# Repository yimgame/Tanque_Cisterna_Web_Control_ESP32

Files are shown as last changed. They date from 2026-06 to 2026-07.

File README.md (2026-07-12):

# Control de bomba para tanque con cisterna por ESP32

Proyecto para controlar una bomba con una ESP32, dos sensores ultrasónicos y un relé. El sistema publica una interfaz web en la propia placa para ver el estado del tanque y la cisterna, habilitar control manual, cambiar el WiFi y acceder por IP o por mDNS.

## Qué incluye

- Servidor web local en la ESP32.
- Medición de cisterna y tanque en tiempo real.
- Modo automático con lógica de llenado.
- Arranque manual con modal de confirmación.
- Arranque manual directo del relé (independiente de niveles), con corte por tiempo máximo.
- Cambio de credenciales WiFi desde ruta oculta de configuración.
- Ruta `/log` con bitácora de acciones (IP, fecha/hora cuando hay NTP).
- Histograma de consumo de agua estimado por hora.
- Acceso por IP local y por `http://tanque.local/`.

## Materiales

- 1 ESP32 compatible, por ejemplo NodeMCU 32S.
- 2 sensores ultrasónicos.
- 1 relé para la bomba.
- Fuente y cableado adecuados para tu instalación.

## Requisitos

1. Instala y abre **[Arduino IDE](https://docs.arduino.cc/software/ide/)**.
2. Configura el soporte de ESP32 en el IDE.
3. Si tu placa no comunica, instala el driver correcto, por ejemplo **[WCH CH340 Driver](https://www.tecneu.com/blogs/tutoriales-de-electronica/guia-paso-a-paso-para-instalar-el-driver-ch340g-en-windows-y-mac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)** o **[Silicon Labs CP210x](https://community.silabs.com/s/question/0D58Y00008K88dCSAR/how-to-download-cp210x-usb-to-uart-bridge-vcp-drivers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)**.
4. Asegúrate de tener las librerías necesarias para ESP32 y WiFiManager.

## Uso

1. Abre el proyecto en Arduino IDE.
2. Compila y sube el sketch que está en [sketch/sketch.ino](sketch/sketch.ino).
3. La primera vez, la ESP32 abrirá el portal de WiFiManager para conectar a tu red.
4. Una vez conectada, revisa el monitor serie: ahí verás la IP local y la URL de acceso.
5. También puedes entrar desde la web con la IP mostrada o con `http://tanque.local/` si tu red resuelve mDNS.

## Prueba rápida

- En el simulador de Wokwi puedes probar la lógica y mover los sensores.
- Proyecto de referencia: https://wokwi.com/projects/467575637641711617

## Nota sobre red

La interfaz web ya no depende de editar manualmente `ssid` y `password`. La red se gestiona con WiFiManager.

Para cambiar credenciales guardadas, entra a la ruta oculta `http://tanque.local/config` (o `http://IP_LOCAL/config`) y usa la opción **CAMBIAR WIFI**.

En esa misma pantalla también puedes guardar la configuración de control del sistema:

- Diámetro y altura de tanque y cisterna.
- Caudal de la bomba en L/min.
- Distancia de lleno y vacío para tanque y cisterna.
- Distancia actual medida por cada sensor.

El sketch calcula la capacidad de cada depósito a partir de diámetro y altura, y usa la calibración de distancias para determinar los arranques y paradas.

En esa misma ruta `/config` tienes el acceso a **VER LOG**, que abre `http://tanque.local/log`.

La conexión queda en DHCP por defecto para que el autoconectado sea más estable, pero ahora también puedes cargar IP manual desde el mismo portal.

### Modo simultáneo: DHCP + IP manual

En el portal de WiFiManager verás los campos de IP, gateway, máscara y DNS.

1. Si dejas esos campos vacíos, la ESP32 conecta por DHCP (automático).
2. Si completas esos campos, la ESP32 conecta con IP manual (estática).

### Opcional avanzado: IP manual por código

Si prefieres dejar fija la IP desde el código, el sketch también está preparado con un ejemplo.

1. Abre [sketch/sketch.ino](sketch/sketch.ino).
2. Busca el bloque `CONFIGURACIÓN DE IP MANUAL (ESTÁTICA)`.
3. Descomenta estas 4 líneas y ajusta los valores a tu red:
	- `IP_MANUAL(192, 168, 0, 34)`
	- `GW_MANUAL(192, 168, 0, 1)`
	- `MASK_MANUAL(255, 255, 255, 0)`
	- `DNS_MANUAL(8, 8, 8, 8)`
4. En `setup()`, descomenta esta línea:
	- `wifiManager.setSTAStaticIPConfig(IP_MANUAL, GW_MANUAL, MASK_MANUAL, DNS_MANUAL);`
5. Compila y vuelve a subir el sketch.

Si dejas todo comentado, seguirá usando el modo simultáneo del portal (DHCP por defecto con opción manual).

## Control manual y seguridad

1. El botón **ARRANQUE** muestra un modal de advertencia antes de activar el relé.
2. Al confirmar, el relé puede encender en modo manual directo (salta la lógica automática de niveles).
3. El botón **PARADA** corta el relé manual.
4. El botón **AUTO / RESET** vuelve al modo automático.
5. El límite de seguridad de 10 minutos sigue activo incluso en modo manual directo.

## Logs y consumo

1. Entra a `http://tanque.local/config`.
2. Abre **VER LOG** para ir a `http://tanque.local/log`.
3. Allí verás la bitácora de comandos con acción, IP cliente y marca de tiempo.
4. También verás un histograma de consumo estimado (L/h), calculado por variación del tanque.
5. Si no hay hora sincronizada por red, la marca de tiempo se guarda como uptime.

## Primera conexión

1. Conéctate desde el celular o PC a la red WiFi que levanta la ESP32 (portal de WiFiManager).
2. Elige tu red WiFi de casa y escribe la contraseña.
3. Guarda y sal del portal. La red temporal de la ESP32 se cierra.
4. Vuelve a conectarte a tu red normal y entra a `http://tanque.local` o a la IP mostrada por el monitor serie.

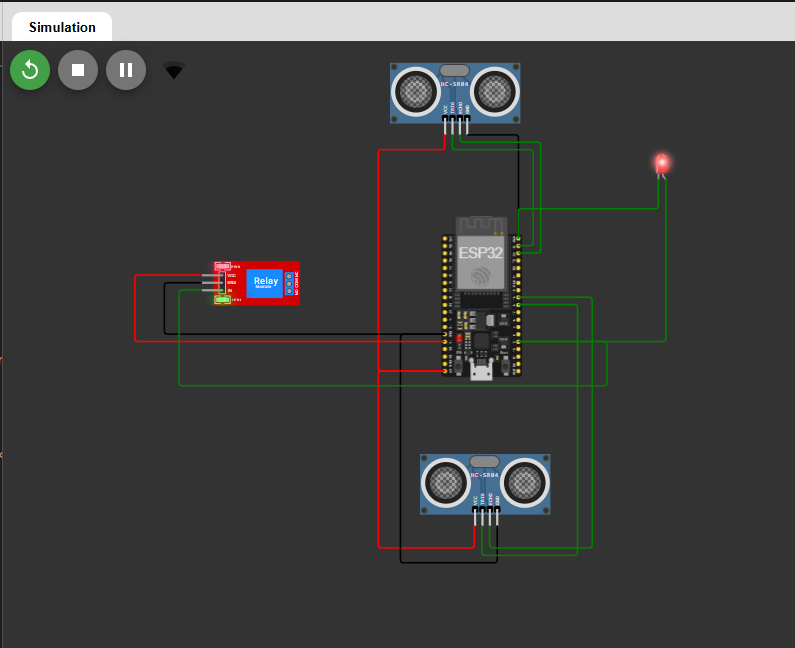
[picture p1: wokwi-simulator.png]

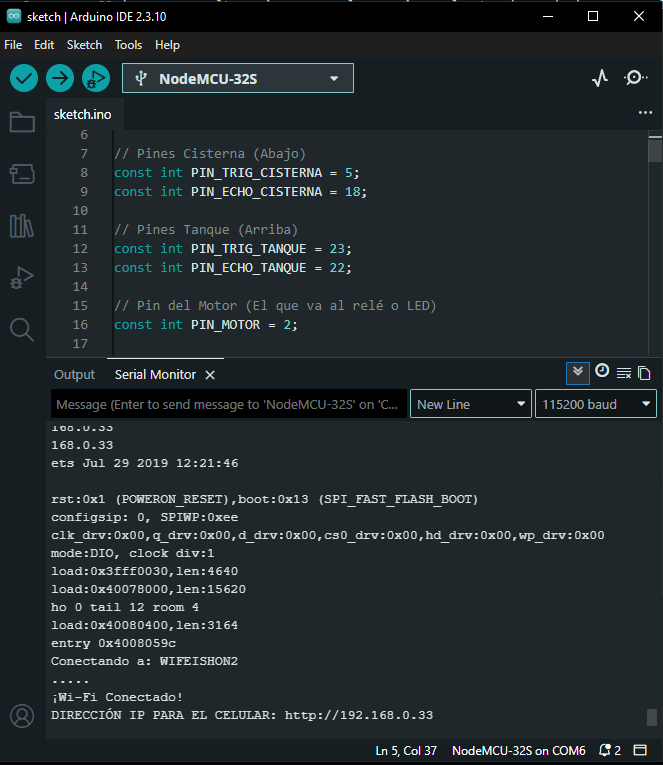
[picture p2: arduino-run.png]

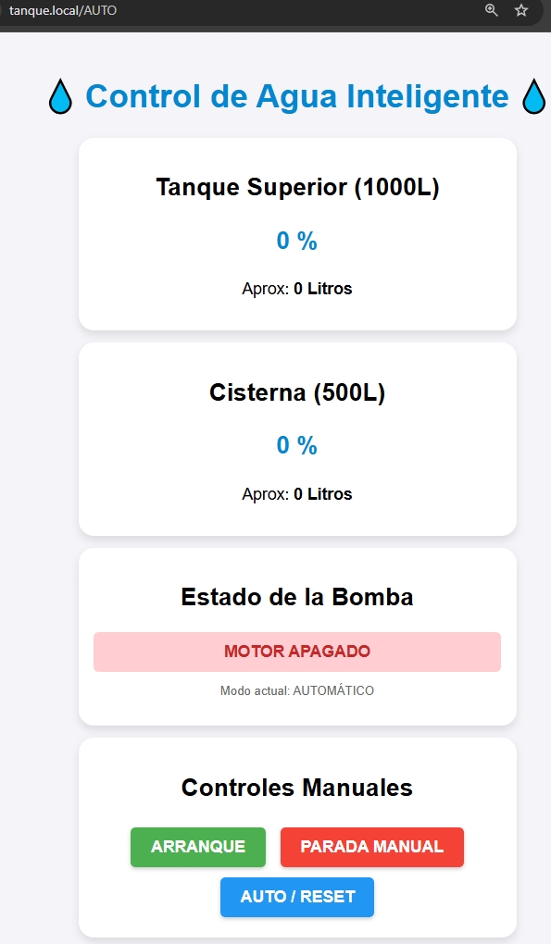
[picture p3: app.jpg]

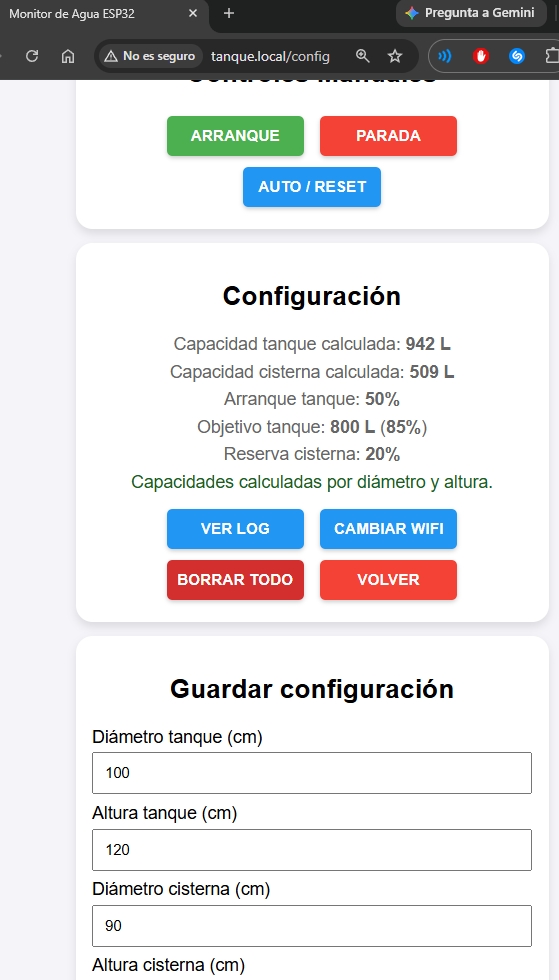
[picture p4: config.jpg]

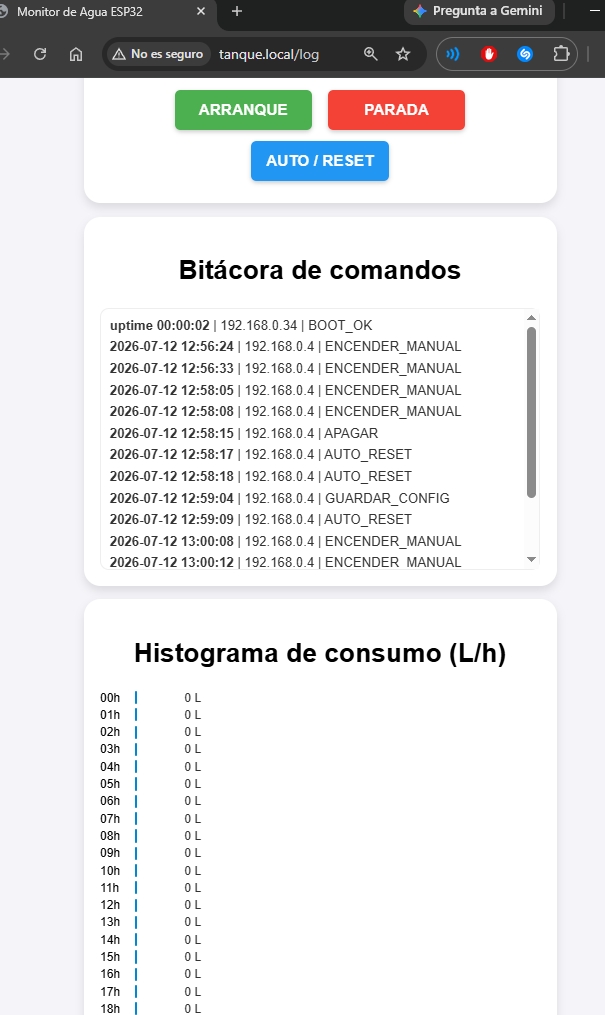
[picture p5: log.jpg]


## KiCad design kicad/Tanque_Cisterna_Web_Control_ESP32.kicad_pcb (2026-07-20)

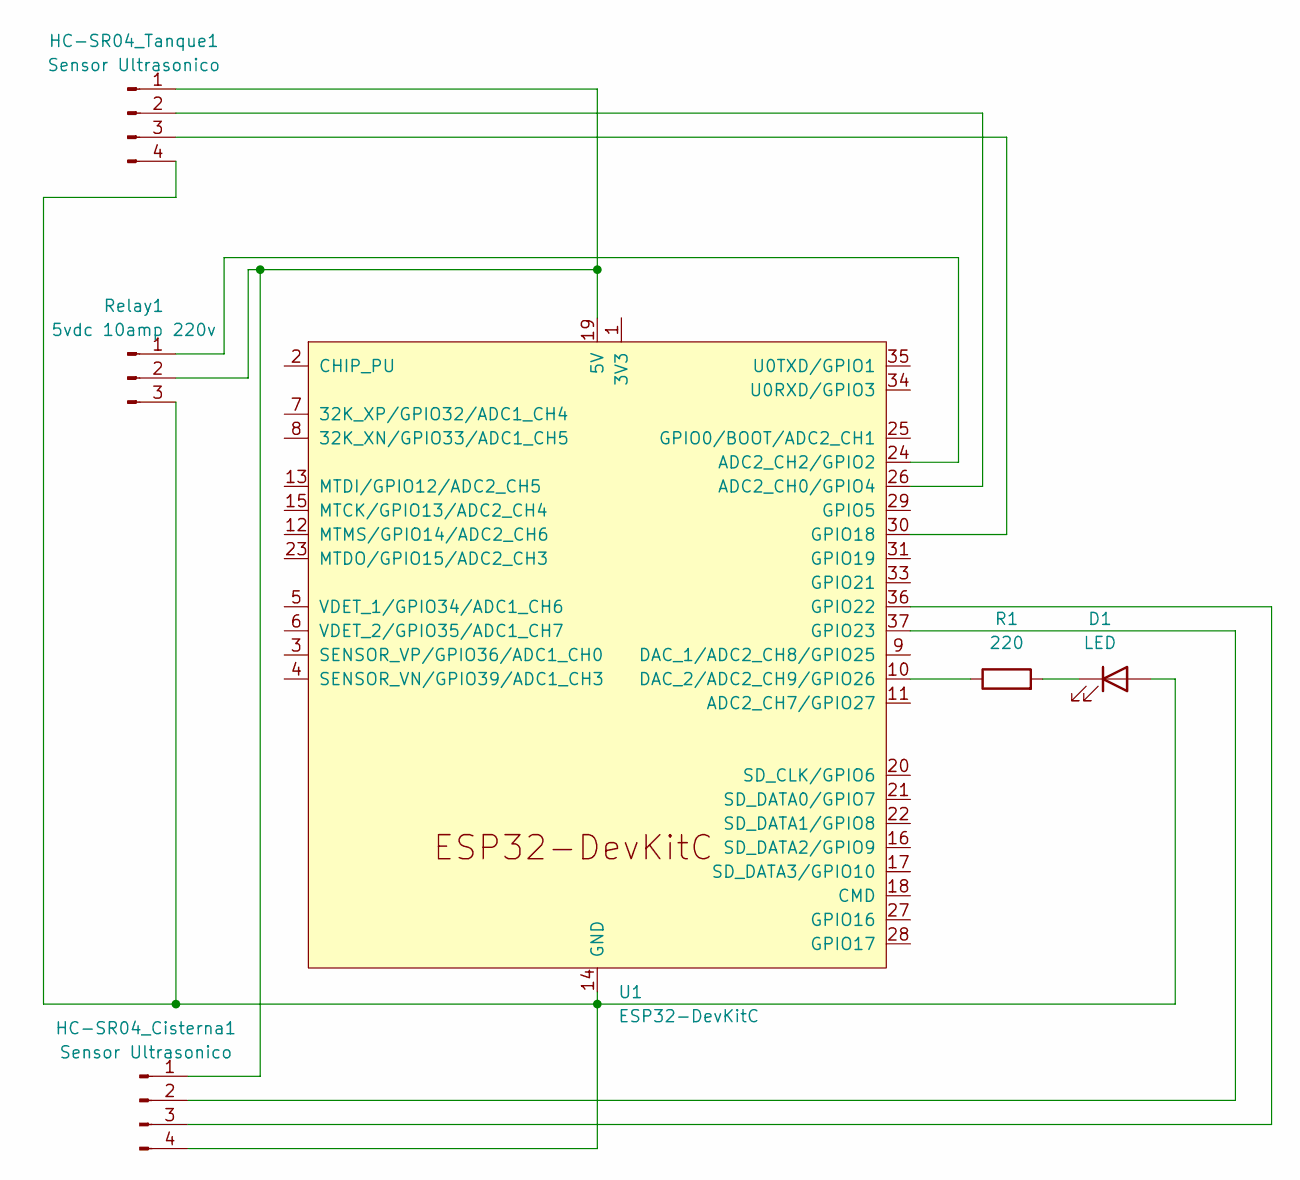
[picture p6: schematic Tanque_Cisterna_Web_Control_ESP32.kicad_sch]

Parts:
D1: LED; LED_D5.0mm
HC-SR04_Cisterna1, HC-SR04_Tanque1: Sensor Ultrasonico; PinSocket_1x04_P2.54mm_Vertical
R1: 220; R_Axial_DIN0207_L6.3mm_D2.5mm_P7.62mm_Horizontal
Relay1: 5vdc 10amp 220v; PinSocket_1x03_P2.54mm_Vertical
U1: ESP32-DevKitC

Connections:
unnamed: D1.2 (A), HC-SR04_Cisterna1.4, HC-SR04_Tanque1.4, Relay1.3, U1.14 (GND), U1.32 (GND), U1.38 (GND)
unnamed: D1.1 (K), R1.2
unnamed: HC-SR04_Cisterna1.1, HC-SR04_Tanque1.1, Relay1.2, U1.19 (5V)
unnamed: HC-SR04_Cisterna1.2, U1.37 (GPIO23)
unnamed: HC-SR04_Cisterna1.3, U1.36 (GPIO22)
unnamed: HC-SR04_Tanque1.2, U1.26 (ADC2_CH0/GPIO4)
unnamed: HC-SR04_Tanque1.3, U1.30 (GPIO18)
unnamed: Relay1.1, U1.24 (ADC2_CH2/GPIO2)
unnamed: R1.1, U1.10 (DAC_2/ADC2_CH9/GPIO26)

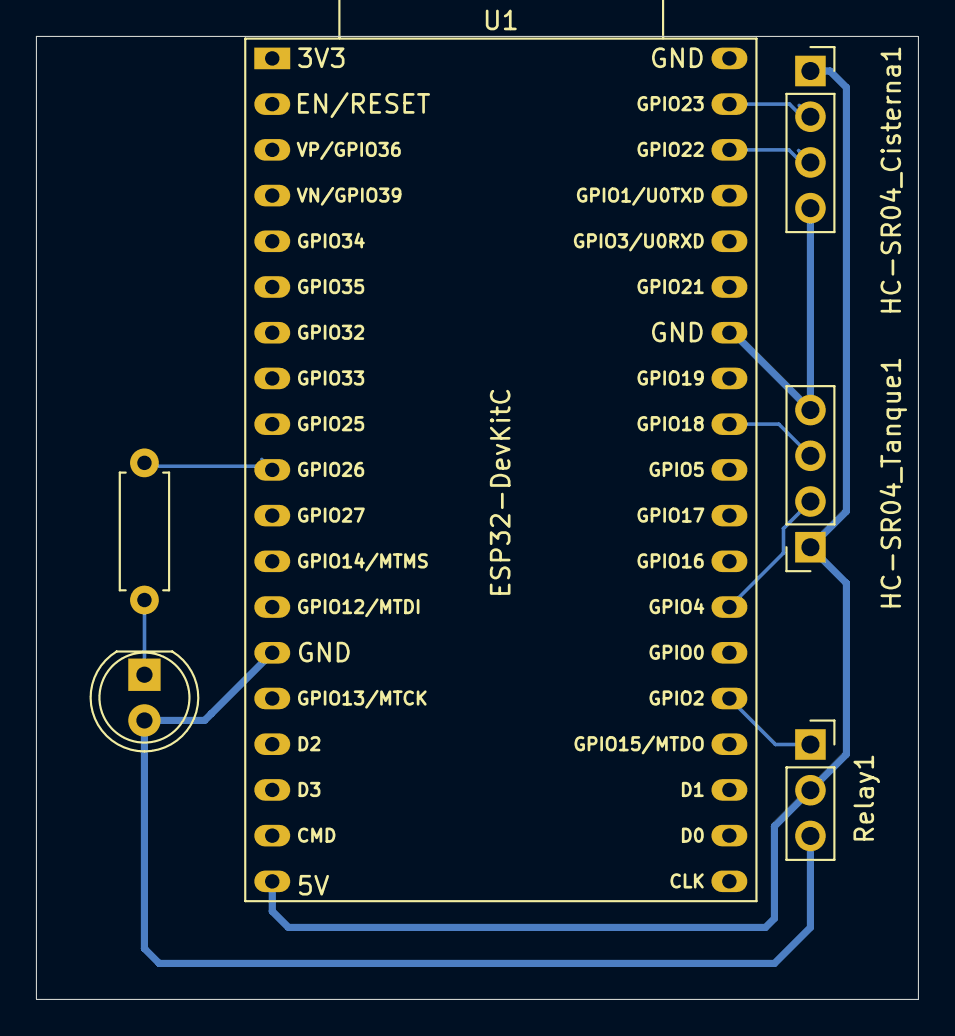
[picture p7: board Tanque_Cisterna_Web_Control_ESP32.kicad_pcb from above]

Board: 2 copper layers, 49.0 x 53.5 mm, 6 parts (0 on the bottom side), 9 nets.

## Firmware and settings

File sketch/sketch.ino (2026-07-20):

#include <DNSServer.h> // Servidor DNS para el portal de configuración WiFiManager
#include <ESPmDNS.h>   // mDNS para "tanque.local"
#include <Preferences.h> // Librería para almacenamiento persistente en la memoria flash del ESP32
#include <WebServer.h>   // Servidor web para la interfaz de usuario
#include <WiFi.h>        // Librería WiFi para ESP32
#include <WiFiManager.h> // Configuración wifi
#include <time.h> // Librería para obtener la hora de red (NTP) y formatearla

// Pines Cisterna (Abajo)
const int PIN_TRIG_CISTERNA = 4;
const int PIN_ECHO_CISTERNA = 18;

// Pines Tanque (Arriba)
const int PIN_TRIG_TANQUE = 23;
const int PIN_ECHO_TANQUE = 22;

// Pin del Motor
const int PIN_MOTOR = 2;

// Pin del LED
const int PIN_LED = 26; // led de motor funcionando prende cuando arranca y se
                        // apaga cuando se detiene

// --- CONFIGURACIÓN DEL SISTEMA ---
const int CAPACIDAD_CISTERNA_FALLBACK_LITROS = 100;
const int CAPACIDAD_TANQUE_FALLBACK_LITROS = 100;

// Valores geométricos y de control por defecto
const int DIAMETRO_CISTERNA_DEF_CM = 50;
const int ALTURA_CISTERNA_DEF_CM = 90;
const int DIAMETRO_TANQUE_DEF_CM = 50;
const int ALTURA_TANQUE_DEF_CM = 90;
const float CAUDAL_BOMBA_DEF_LPM = 20.0f;

// Nuevos parámetros de control unificados en porcentajes
const int TANQUE_ARRANQUE_DEF_PORCENTAJE = 10;  // Default 10%
const int TANQUE_CORTE_DEF_PORCENTAJE = 95;     // Default 95%
const int CISTERNA_RESERVA_DEF_PORCENTAJE = 10; // Default 10%
const int CISTERNA_MAX_DEF_PORCENTAJE = 95;     // Default 95%

const int CAPTURAS_PROMEDIO_DEF = 10;
const int CAPTURAS_PROMEDIO_MAX = 50;
const int TIEMPO_ESPERA_ENTRE_ARRANQUES_DEF_MIN = 60;
const int TIEMPO_ESPERA_ENTRE_ARRANQUES_MIN_MIN = 5;
const int TIEMPO_ESPERA_ENTRE_ARRANQUES_MAX_MIN = 240;

int diametroCisternaCm = DIAMETRO_CISTERNA_DEF_CM;
int alturaCisternaCm = ALTURA_CISTERNA_DEF_CM;
int diametroTanqueCm = DIAMETRO_TANQUE_DEF_CM;
int alturaTanqueCm = ALTURA_TANQUE_DEF_CM;
float caudalBombaLpm = CAUDAL_BOMBA_DEF_LPM;

int tanqueArranquePorcentaje = TANQUE_ARRANQUE_DEF_PORCENTAJE;
int tanqueCortePorcentaje = TANQUE_CORTE_DEF_PORCENTAJE;
int cisternaReservaPorcentaje = CISTERNA_RESERVA_DEF_PORCENTAJE;
int cisternaMaxPorcentaje = CISTERNA_MAX_DEF_PORCENTAJE;

int capturasPromedio = CAPTURAS_PROMEDIO_DEF;
int tiempoEsperaEntreArranquesMin = TIEMPO_ESPERA_ENTRE_ARRANQUES_DEF_MIN;

int muestrasCisterna[CAPTURAS_PROMEDIO_MAX] = {0};
int muestrasTanque[CAPTURAS_PROMEDIO_MAX] = {0};
long sumaMuestrasCisterna = 0;
long sumaMuestrasTanque = 0;
int indiceMuestra = 0;
int cantidadMuestras = 0;

const unsigned long TIEMPO_SEGURIDAD_MINIMO_BOMBA_MS = 10UL * 60UL * 1000UL;
const unsigned long TIEMPO_SEGURIDAD_MINIMO_CALCULADO_MS = 60UL * 1000UL;
const float FACTOR_SEGURIDAD_BOMBA = 1.2f;

// --- VARIABLES DE ESTADO ---
bool motorEncendido = false;
bool bloqueoSeguridad = false;
bool reiniciarParaConfigWiFi = false;
bool releManualDirecto = false;
bool pedidoArranqueAutomatico = false;
unsigned long tiempoInicioBomba = 0;
unsigned long tiempoFuncionando = 0;
unsigned long tiempoMaximoBombaMs = TIEMPO_SEGURIDAD_MINIMO_BOMBA_MS;
unsigned long proximoArranquePermitidoMs = 0;
String accesoWebIp = "";
String accesoWebMdns = "http://tanque.local/";
unsigned long ultimaSalidaSerialSensores = 0;
const unsigned long INTERVALO_SERIAL_SENSORES_MS = 1000;

int modoManual = 0;

WiFiManager wifiManager;
Preferences preferences;
String mensajeConfig = "";

// --- LOGS Y CONSUMO DE AGUA ---
const int MAX_LOGS = 40;
const unsigned long INTERVALO_CONSUMO_MS = 30000;

struct EventoLog {
  String momento;
  String ip;
  String accion;
};

EventoLog logs[MAX_LOGS];
int logInicio = 0;
int logCantidad = 0;
float histConsumoLitros[24] = {0};
unsigned long ultimoMuestreoConsumo = 0;
int ultimoLitrosTanqueMuestreo = -1;

void guardarHistorialConsumo() {
  preferences.begin("consumo", false);
  preferences.putBytes("hist24", histConsumoLitros, sizeof(histConsumoLitros));
  preferences.end();
}

void cargarHistorialConsumo() {
  preferences.begin("consumo", true);
  size_t leidos = preferences.getBytes("hist24", histConsumoLitros,
                                       sizeof(histConsumoLitros));
  preferences.end();

  if (leidos != sizeof(histConsumoLitros)) {
    for (int i = 0; i < 24; i++) {
      histConsumoLitros[i] = 0;
    }
  }
}

void borrarHistorialConsumo() {
  for (int i = 0; i < 24; i++) {
    histConsumoLitros[i] = 0;
  }
  guardarHistorialConsumo();
}

void borrarPersistenciaConsumo() {
  preferences.begin("consumo", false);
  preferences.remove("hist24");
  preferences.end();
  borrarHistorialConsumo();
}

String marcaTiempoActual() {
  struct tm info;
  if (getLocalTime(&info, 5)) {
    char buffer[24];
    strftime(buffer, sizeof(buffer), "%Y-%m-%d %H:%M:%S", &info);
    return String(buffer);
  }

  unsigned long totalSeg = millis() / 1000;
  unsigned long hh = totalSeg / 3600;
  unsigned long mm = (totalSeg % 3600) / 60;
  unsigned long ss = totalSeg % 60;
  char buffer[24];
  snprintf(buffer, sizeof(buffer), "uptime %02lu:%02lu:%02lu", hh, mm, ss);
  return String(buffer);
}

String obtenerRazonReinicio() {
  esp_reset_reason_t reason = esp_reset_reason();
  switch (reason) {
  case ESP_RST_POWERON:
    return "Encendido (Power-on)";
  case ESP_RST_EXT:
    return "Pin de Reset (External pin)";
  case ESP_RST_SW:
    return "Reinicio por Software";
  case ESP_RST_PANIC:
    return "Excepcion de Software (Crash)";
  case ESP_RST_INT_WDT:
    return "Watchdog de Interrupcion";
  case ESP_RST_TASK_WDT:
    return "Watchdog de Tarea (Task WDT)";
  case ESP_RST_WDT:
    return "Otros Watchdogs";
  case ESP_RST_DEEPSLEEP:
    return "Despierto de Deep Sleep";
  case ESP_RST_BROWNOUT:
    return "Baja Tension (Brownout)";
  case ESP_RST_SDIO:
    return "Reset SDIO";
  default:
    return "Desconocido";
  }
}

void registrarEvento(const String &accion, const String &ip) {
  int idx = (logInicio + logCantidad) % MAX_LOGS;
  logs[idx].momento = marcaTiempoActual();
  logs[idx].ip = ip;
  logs[idx].accion = accion;

  if (logCantidad < MAX_LOGS) {
    logCantidad++;
  } else {
    logInicio = (logInicio + 1) % MAX_LOGS;
  }
}

int obtenerHoraHistograma() {
  struct tm info;
  if (getLocalTime(&info, 5)) {
    return info.tm_hour;
  }
  return (millis() / 3600000UL) % 24;
}

void actualizarHistogramaConsumo(int litrosTanque) {
  unsigned long ahora = millis();
  if (ultimoLitrosTanqueMuestreo < 0) {
    ultimoLitrosTanqueMuestreo = litrosTanque;
    ultimoMuestreoConsumo = ahora;
    return;
  }

  if (ahora - ultimoMuestreoConsumo < INTERVALO_CONSUMO_MS) {
    return;
  }

  int delta = ultimoLitrosTanqueMuestreo - litrosTanque;
  if (delta >= 2) {
    int h = obtenerHoraHistograma();
    histConsumoLitros[h] += delta;
    guardarHistorialConsumo();
  }

  ultimoLitrosTanqueMuestreo = litrosTanque;
  ultimoMuestreoConsumo = ahora;
}

String obtenerRutaSolicitud(const String &request) {
  int inicio = request.indexOf("GET /");
  if (inicio < 0)
    return "";
  int fin = request.indexOf(' ', inicio + 5);
  if (fin < 0)
    return "";
  return request.substring(inicio + 5, fin);
}

String obtenerParametroConsulta(const String &ruta, const String &nombre) {
  int pregunta = ruta.indexOf('?');
  if (pregunta < 0)
    return "";
  String consulta = ruta.substring(pregunta + 1);
  String marca = nombre + "=";
  int inicio = consulta.indexOf(marca);
  if (inicio < 0)
    return "";
  inicio += marca.length();
  int fin = consulta.indexOf('&', inicio);
  if (fin < 0)
    fin = consulta.length();
  String valor = consulta.substring(inicio, fin);
  valor.replace("+", " ");
  return valor;
}

int leerParametroEntero(const String &ruta, const String &nombre,
                        int valorActual, int minimo, int maximo) {
  String valor = obtenerParametroConsulta(ruta, nombre);
  if (valor.length() == 0)
    return valorActual;
  return constrain(valor.toInt(), minimo, maximo);
}

float leerParametroFloat(const String &ruta, const String &nombre,
                         float valorActual, float minimo, float maximo) {
  String valor = obtenerParametroConsulta(ruta, nombre);
  if (valor.length() == 0)
    return valorActual;
  float nuevoValor = valor.toFloat();
  return constrain(nuevoValor, minimo, maximo);
}

int calcularCapacidadCilindricaLitros(int diametroCm, int alturaCm,
                                      int capacidadFallbackLitros) {
  if (diametroCm <= 0 || alturaCm <= 0)
    return capacidadFallbackLitros;
  float radioCm = diametroCm / 2.0f;
  float volumenCm3 = 3.14159265f * radioCm * radioCm * alturaCm;
  int litros = (int)(volumenCm3 / 1000.0f + 0.5f);
  return (litros <= 0) ? capacidadFallbackLitros : litros;
}

// NUEVA FUNCIÓN: Traduce el porcentaje deseado a distancia física en cm
// basándose en la altura total
int calcularDistanciaDesdePorcentaje(int porcentaje, int alturaTotalCm) {
  if (alturaTotalCm <= 0)
    return 0;
  float factorVacío = (100.0f - porcentaje) / 100.0f;
  return (int)(alturaTotalCm * factorVacío + 0.5f);
}

// Nueva lectura limpia del porcentaje según la lectura actual del sensor y la
// física del contenedor
int calcularPorcentajeDesdeMedicion(int distanciaCm, int alturaTotalCm) {
  if (alturaTotalCm <= 0)
    return 0;
  int distanciaAjustada = constrain(distanciaCm, 0, alturaTotalCm);
  float pct =
      ((float)(alturaTotalCm - distanciaAjustada) / alturaTotalCm) * 100.0f;
  return constrain((int)(pct + 0.5f), 0, 100);
}

void reiniciarPromedioSensores() {
  sumaMuestrasCisterna = 0;
  sumaMuestrasTanque = 0;
  indiceMuestra = 0;
  cantidadMuestras = 0;
}

unsigned long obtenerCooldownAnticicloMs() {
  int minutos = constrain(tiempoEsperaEntreArranquesMin,
                          TIEMPO_ESPERA_ENTRE_ARRANQUES_MIN_MIN,
                          TIEMPO_ESPERA_ENTRE_ARRANQUES_MAX_MIN);
  return (unsigned long)minutos * 60UL * 1000UL;
}

unsigned long obtenerCooldownRestanteMs() {
  if (proximoArranquePermitidoMs == 0)
    return 0;
  unsigned long ahora = millis();
  if (ahora >= proximoArranquePermitidoMs)
    return 0;
  return proximoArranquePermitidoMs - ahora;
}

String obtenerTextoEstadoBomba() {
  if (bloqueoSeguridad)
    return "BLOQUEO DE SEGURIDAD";
  unsigned long cooldownRestanteMs = obtenerCooldownRestanteMs();
  if (cooldownRestanteMs > 0 && !motorEncendido && modoManual == 0 &&
      !releManualDirecto) {
    return "EN COOLDOWN - restan " +
           String((cooldownRestanteMs / 1000UL) / 60) + " min " +
           String((cooldownRestanteMs / 1000UL) % 60) + " seg";
  }
  if (motorEncendido)
    return "BOMBEANDO AGUA...";
  return "MOTOR APAGADO";
}

bool guardarConfiguracionDesdeRuta(const String &ruta, String &error) {
  int nuevoDiametroTanqueCm =
      leerParametroEntero(ruta, "diam_tanque", diametroTanqueCm, 0, 500);
  int nuevaAlturaTanqueCm =
      leerParametroEntero(ruta, "alto_tanque", alturaTanqueCm, 1, 500);
  int nuevoDiametroCisternaCm =
      leerParametroEntero(ruta, "diam_cisterna", diametroCisternaCm, 0, 500);
  int nuevaAlturaCisternaCm =
      leerParametroEntero(ruta, "alto_cisterna", alturaCisternaCm, 1, 500);
  float nuevoCaudalBombaLpm =
      leerParametroFloat(ruta, "caudal_bomba", caudalBombaLpm, 0.1f, 9999.0f);

  int nuevoTanqueArranquePorcentaje = leerParametroEntero(
      ruta, "tanque_arranque_pct", tanqueArranquePorcentaje, 0, 100);
  int nuevoTanqueCortePorcentaje = leerParametroEntero(
      ruta, "tanque_corte_pct", tanqueCortePorcentaje, 0, 100);
  int nuevaCisternaReservaPct = leerParametroEntero(
      ruta, "cisterna_reserva_pct", cisternaReservaPorcentaje, 0, 100);
  int nuevaCisternaMaxPct = leerParametroEntero(ruta, "cisterna_max_pct",
                                                cisternaMaxPorcentaje, 0, 100);

  int nuevasCapturasPromedio = leerParametroEntero(
      ruta, "capturas_promedio", capturasPromedio, 1, CAPTURAS_PROMEDIO_MAX);
  int nuevoCooldownAnticicloMin = leerParametroEntero(
      ruta, "cooldown_anticiclo_min", tiempoEsperaEntreArranquesMin,
      TIEMPO_ESPERA_ENTRE_ARRANQUES_MIN_MIN,
      TIEMPO_ESPERA_ENTRE_ARRANQUES_MAX_MIN);

  if (nuevoTanqueArranquePorcentaje >= nuevoTanqueCortePorcentaje) {
    error = "El % de arranque del tanque debe ser menor que el % de corte.";
    return false;
  }
  if (nuevaCisternaReservaPct >= nuevaCisternaMaxPct) {
    error = "La reserva de la cisterna debe ser menor al % máximo de la misma.";
    return false;
  }

  diametroTanqueCm = nuevoDiametroTanqueCm;
  alturaTanqueCm = nuevaAlturaTanqueCm;
  diametroCisternaCm = nuevoDiametroCisternaCm;
  alturaCisternaCm = nuevaAlturaCisternaCm;
  caudalBombaLpm = nuevoCaudalBombaLpm;
  tanqueArranquePorcentaje = nuevoTanqueArranquePorcentaje;
  tanqueCortePorcentaje = nuevoTanqueCortePorcentaje;
  cisternaReservaPorcentaje = nuevaCisternaReservaPct;
  cisternaMaxPorcentaje = nuevaCisternaMaxPct;
  tiempoEsperaEntreArranquesMin = nuevoCooldownAnticicloMin;

  if (capturasPromedio != nuevasCapturasPromedio) {
    capturasPromedio = nuevasCapturasPromedio;
    reiniciarPromedioSensores();
  }

  preferences.begin("tanquecfg", false);
  preferences.putInt("diam_tanque", diametroTanqueCm);
  preferences.putInt("alto_tanque", alturaTanqueCm);
  preferences.putInt("diam_cisterna", diametroCisternaCm);
  preferences.putInt("alto_cisterna", alturaCisternaCm);
  preferences.putFloat("caudal_bomba", caudalBombaLpm);
  preferences.putInt("tanque_arranque_pct", tanqueArranquePorcentaje);
  preferences.putInt("tanque_corte_pct", tanqueCortePorcentaje);
  preferences.putInt("cisterna_reserva_pct", cisternaReservaPorcentaje);
  preferences.putInt("cisterna_max_pct", cisternaMaxPorcentaje);
  preferences.putInt("cooldown_anticiclo_min", tiempoEsperaEntreArranquesMin);
  preferences.putInt("capt_prom", capturasPromedio);
  preferences.end();
  error = "";
  return true;
}
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
void loop() {
  int lecturaCisterna = medirDistancia(PIN_TRIG_CISTERNA, PIN_ECHO_CISTERNA);
  int lecturaTanque = medirDistancia(PIN_TRIG_TANQUE, PIN_ECHO_TANQUE);
  agregarMuestrasSensores(lecturaCisterna, lecturaTanque);

  int capacidadCisternaLitros = calcularCapacidadCilindricaLitros(
      diametroCisternaCm, alturaCisternaCm, CAPACIDAD_CISTERNA_FALLBACK_LITROS);
  int capacidadTanqueLitros = calcularCapacidadCilindricaLitros(
      diametroTanqueCm, alturaTanqueCm, CAPACIDAD_TANQUE_FALLBACK_LITROS);

  // Mapeos dinámicos basados exclusivamente en la altura y lectura de los
  // sensores
  int pctCisterna =
      calcularPorcentajeDesdeMedicion(distCisterna, alturaCisternaCm);
  int pctTanque = calcularPorcentajeDesdeMedicion(distTanque, alturaTanqueCm);

  int litrosCisterna = (int)((pctCisterna / 100.0f) * capacidadCisternaLitros);
  int litrosTanque = (int)((pctTanque / 100.0f) * capacidadTanqueLitros);

  int reservaLitrosCisterna =
      (int)(capacidadCisternaLitros * (cisternaReservaPorcentaje / 100.0f));
  int litrosDisponiblesCisterna =
      max(litrosCisterna - reservaLitrosCisterna, 0);
  int litrosCorteTanque =
      (int)(capacidadTanqueLitros * (tanqueCortePorcentaje / 100.0f));
  int litrosParaObjetivoTanque = max(litrosCorteTanque - litrosTanque, 0);

  actualizarHistogramaConsumo(litrosTanque);

  if (millis() - ultimaSalidaSerialSensores >= INTERVALO_SERIAL_SENSORES_MS) {
    ultimaSalidaSerialSensores = millis();
    Serial.print("Tanque: ");
    Serial.print(pctTanque);
    Serial.print("% | Cisterna: ");
    Serial.print(pctCisterna);
    Serial.println("%");
  }

  // --- LÓGICA AUTOMÁTICA MEJORADA UNIFICADA ---
  bool promedioListo = (cantidadMuestras >= capturasPromedio);
  bool cisternaTieneAgua =
      promedioListo && (pctCisterna > cisternaReservaPorcentaje);
  bool tanqueNecesitaCarga =
      promedioListo && (pctTanque <= tanqueArranquePorcentaje);
  bool tanqueAlcanzoObjetivo =
      (pctTanque >= tanqueCortePorcentaje); // Único criterio inequívoco
  bool enEsperaAnticiclo =
      (proximoArranquePermitidoMs > 0 && millis() < proximoArranquePermitidoMs);
  bool anticicloActivo = enEsperaAnticiclo;
  bool motorDeberiaEncender = motorEncendido;

  if (pctTanque > tanqueArranquePorcentaje &&
      pctTanque < tanqueCortePorcentaje && !motorEncendido) {
    bloqueoSeguridad = false;
  }

  if (!cisternaTieneAgua || tanqueAlcanzoObjetivo || enEsperaAnticiclo) {
    motorDeberiaEncender = false;
  } else if (tanqueNecesitaCarga) {
    motorDeberiaEncender = true;
  }

  if (releManualDirecto) {
    motorEncendido = true;
  } else if (bloqueoSeguridad) {
    motorEncendido = false;
  } else if (modoManual == 1) {
    motorEncendido = cisternaTieneAgua;
  } else if (modoManual == 2) {
    motorEncendido = false;
  } else {
    if (motorEncendido && !motorDeberiaEncender)
      motorEncendido = false;
    else if (!motorEncendido && motorDeberiaEncender && !enEsperaAnticiclo)
      pedidoArranqueAutomatico = true;

    if (pedidoArranqueAutomatico && !enEsperaAnticiclo) {
      motorEncendido = true;
      pedidoArranqueAutomatico = false;
    }
  }

  if (anticicloActivo) {
    motorEncendido = false;
    releManualDirecto = false;
    modoManual = 0;
    pedidoArranqueAutomatico = false;
  }

  if (motorEncendido) {
    if (tiempoInicioBomba == 0) {
      tiempoInicioBomba = millis();
      int litrosUtilesCalculo = max(litrosDisponiblesCisterna, 1);
      if (!releManualDirecto && modoManual == 0) {
        litrosUtilesCalculo =
            min(litrosDisponiblesCisterna, max(litrosParaObjetivoTanque, 1));
      }
      tiempoMaximoBombaMs = calcularTiempoMaximoBombaMs(litrosUtilesCalculo);
    }
    tiempoFuncionando = millis() - tiempoInicioBomba;
    if (tiempoFuncionando >= tiempoMaximoBombaMs) {
      bloqueoSeguridad = true;
      motorEncendido = false;
      modoManual = 0;
      releManualDirecto = false;
    }
  } else {
    bool estabaEncendida = (tiempoInicioBomba != 0);
    tiempoInicioBomba = 0;
    tiempoFuncionando = 0;
    tiempoMaximoBombaMs = TIEMPO_SEGURIDAD_MINIMO_BOMBA_MS;
    if (estabaEncendida && !releManualDirecto && modoManual == 0) {
      proximoArranquePermitidoMs = millis() + obtenerCooldownAnticicloMs();
    }
  }

  digitalWrite(PIN_MOTOR, motorEncendido ? HIGH : LOW);

  // --- SERVIDOR WEB ---
  WiFiClient client = server.available();
  if (client) {
    String currentLine = "";
    String request = "";
    while (client.connected()) {
      if (client.available()) {
        char c = client.read();
        request += c;
        if (c == '\n') {
          if (currentLine.length() == 0) {
            String ipCliente = client.remoteIP().toString();
            String ruta = obtenerRutaSolicitud(request);
            bool enPaginaConfig = ruta.startsWith("config");
            bool enPaginaLog = ruta.startsWith("log");
            bool configGuardada = false;

            if (ruta.startsWith("ENCENDER")) {
              if (obtenerCooldownRestanteMs() == 0) {
                releManualDirecto = true;
                modoManual = 1;
                bloqueoSeguridad = false;
                pedidoArranqueAutomatico = false;
                registrarEvento("ENCENDER_MANUAL", ipCliente);
              } else {
                mensajeConfig = "No se permite encender durante el cooldown.";
              }
            }
            if (ruta.startsWith("APAGAR")) {
              releManualDirecto = false;
              modoManual = 2;
              pedidoArranqueAutomatico = false;
              registrarEvento("APAGAR", ipCliente);
            }
            if (ruta.startsWith("AUTO")) {
              releManualDirecto = false;
              modoManual = 0;
              bloqueoSeguridad = false;
              proximoArranquePermitidoMs = 0;
              pedidoArranqueAutomatico = false;
              registrarEvento("AUTO_RESET", ipCliente);
              client.println("HTTP/1.1 302 Found\r\nLocation: /\r\nConnection: "
                             "close\r\n\r\n");
              break;
            }
            if (ruta.startsWith("config/cambiar_wifi")) {
              reiniciarParaConfigWiFi = true;
              wifiManager.resetSettings();
              registrarEvento("CAMBIAR_WIFI", ipCliente);
            }
            if (ruta.startsWith("config/borrar_consumo")) {
              borrarPersistenciaConsumo();
              configGuardada = true;
              registrarEvento("BORRAR_CONSUMO", ipCliente);
            }
            if (ruta.startsWith("config/guardar")) {
              String errorGuardar = "";
              if (guardarConfiguracionDesdeRuta(ruta, errorGuardar)) {
                configGuardada = true;
                registrarEvento("GUARDAR_CONFIG", ipCliente);
              } else {
                mensajeConfig = errorGuardar;
              }
            }
            if (ruta.startsWith("config/borrar_datos")) {
              borrarTodoPersistido();
              configGuardada = true;
              registrarEvento("BORRAR_DATOS", ipCliente);
            }
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

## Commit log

2026-06-23 Tanque Cisterna primer commit, codigo testeado en simulador wokwi y en la ESP32 hardware
    https://wokwi.com/projects/467575637641711617
2026-06-23 Revise ESP32 setup instructions in README
    Updated instructions for setting up ESP32 with Arduino IDE, including driver installation and WiFi configuration.
2026-06-23 Revise README setup instructions for ESP32 project
    Updated setup instructions and improved clarity.
2026-06-24 Fix typo in sensor description in README.md
2026-06-27 Se agregaron botones de encendido parada, ahora calcula los litros tanque 1000 cistrerna 500 litros, tiene un timer de funcionamioento por tiempo que para a los 10 min segun los 33 litros por min de 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
2026-06-27 Nueva app web con hostname http://tanque.local se agregaron botones de arranque parada, timer de funcionamiento 10 min para 500 litros con una centrifuga bomba de 33 l/m y datos de capacidad aprox pa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
2026-06-28 Corrección de la logica de arranque manual, detalle de tamaño de botones parejos.
2026-07-10 Resumen para el commit:
2026-07-12 Se agrego config avanzada con parametros de tanque cisterna diametro altura caudal de bomba umbrales de arranque y parada por distancia de sensor y objetivos en litro que controlan de no pasar la cap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
2026-07-12 Se corrige calculo de tiempo de bomba en funciona de la cisterna y caudal de bomba mas presicion antes mostaba 10 min
    [sketch.ino]
2026-07-12 Se agregan imagenes de config y log
2026-07-18 Se agrego sistema json de actualizacion en tiempo real sin refrescar la web, se agrego en config un box con la info del serial de tanque y cisterna, se agergo un sistema circular que promedia las ult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
2026-07-19 Se agrego coldown de motor seteable por config, ante un parada luego de cargar, espera el tiempo seteado y evitar rebotes por datos erroneos del sensor, borrado de historial de consumo y limite de al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
2026-07-19 Se corrige error que actualizaba el estado de bomba en la web al refrescar, se detecto al mostrar el coldown en la web, ahora el estado de la bomba se muestra persistente hasta que se resetea de mane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
    [sketch.ino]
2026-07-19 Se refactorizo el formulario bazado en porcentajes, mejora en el cooldown de parada, ahora el boton auto reset re envia a home al ejecutar, se re organizo el home, config y log por separado
    [sketch.ino]
2026-07-20 Se agregan archivos de diseño de pcb kikad esquematico pistas gbr y dril proyecto bcut y demas files exportados v.01 full listo para manda a pcbway
    [Tanque_Cisterna_Web_Control_ESP32-B_Cu.gbr, Tanque_Cisterna_Web_Control_ESP32-B_Mask.gbr, Tanque_Cisterna_Web_Control_ESP32-B_Paste.gbr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]
